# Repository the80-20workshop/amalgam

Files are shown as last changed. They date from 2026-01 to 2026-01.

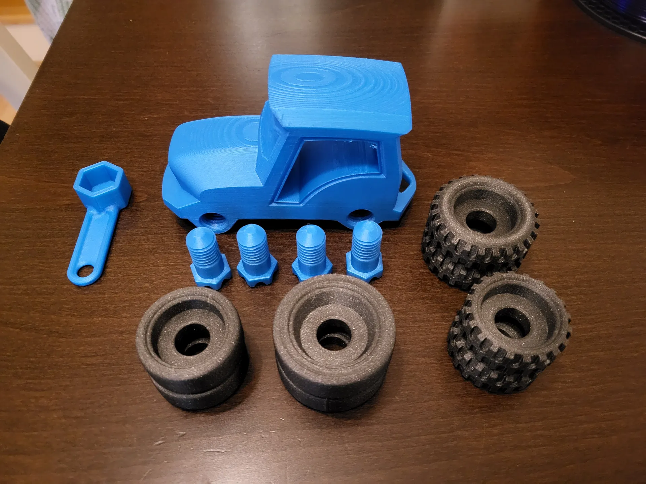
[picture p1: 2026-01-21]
docs/reference/ai-conversations/17003388837447721058862837478401.webp

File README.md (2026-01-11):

# Neo-Darwin

### A 2026 RepRap Reference Specification

**High-Mass, Low-Cost, Total Control.**

---

## 🚜 The Tractor is Coming

Neo-Darwin is a reimagining of the 2007 RepRap Darwin — a high-mass, fully parametric 3D printer built from M12 threaded rod, salvaged components, and open-source intelligence.

**Expected Release:** Q2/Q3 2026

---

## The Philosophy

We build a **"Tractor with the Brain of a Racecar"** — using heavy, high-torque, battle-tested hardware and giving it extreme precision through Klipper.

| Feature | Target |
|---|---|
| **Price** | < $300 AUD |
| **Build Volume** | 250–300mm³ |
| **Accuracy** | ±0.1mm (Tier 3+) |
| **Speed** | 70–120mm/s |
| **Control** | 100% Local, No Cloud |

---

## The Lineage

* **[RepRap Darwin (2007)](https://reprap.org/wiki/Darwin):** The origin. We carry its name forward.
* **[Prusa i3 Rework (2013)](https://www.thingiverse.com/thing:119616):** The source of our geared extruder heritage.
* **[RepRap Mendel Revisited (2024)](https://www.thingiverse.com/thing:6783269):** A modern nod to the M12 skeleton.
* **[The 100](https://github.com/MSzturc/the100) / [The Rook](https://github.com/Kanrog/Rook) (2023):** Proof that Klipper makes DIY frames competitive.

---

## 🚀 Getting Started

Want to build Neo-Darwin parts?

1. **Clone the repository**:
   ```bash
   git clone https://github.com/neo-darwin-reprap/neo-darwin.git
   cd neo-darwin
   ```

2. **Build parts**:
   ```bash
   cd cad
   ./setup.sh
   ```

3. **Learn more**:
   - [BUILDING.md](BUILDING.md) - Complete build guide
   - [cad/README.md](cad/README.md) - CAD documentation

**Requirements:**
- Python 3.9+
- 4GB RAM (recommended)
- See [BUILDING.md](BUILDING.md) for platform-specific setup

## Status

| Component | Status |
|---|---|
| Manifesto | ✅ Complete |
| build123d Parametric Parts | 🔧 In Development |
| Klipper Configurations | 🔧 In Development |
| Assembly Documentation | ⏳ Planned |
| Reference Build | ⏳ Planned |

---

## Stay Updated

⭐ **Star this repo** to follow development.

📬 **Discussions** will open closer to release.

---

## License

**GNU GPL v3** — The same license used by the original RepRap Darwin.

---

> *If you want a printer, buy one. If you want the Red Pill, build this.*

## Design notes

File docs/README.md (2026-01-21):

# Neo-Darwin Documentation

This directory contains all project documentation for Neo-Darwin.

## Documentation Structure

```
docs/
├── adr/           # Architecture Decision Records (formal decisions)
├── analysis/      # Engineering calculations and analysis
├── articles/      # Long-form thought pieces
├── deep-dives/    # Design exploration documents
├── guides/        # Tier-specific build guides
│   └── klipper/   # Klipper host setup guides
└── reference/     # Historical AI conversations (archival)
```

---

## Quick Navigation

### Getting Started

| Document | Description |
|---|---|
| [../MANIFESTO.md](../MANIFESTO.md) | Project overview and quick-start |
| [../PHILOSOPHY.md](../PHILOSOPHY.md) | The "Tractor" philosophy |
| [../REFERENCE-SPEC.md](../REFERENCE-SPEC.md) | Hardware specification |
| [../BUILDING.md](../BUILDING.md) | CAD/STL generation |

### Architecture Decisions

| ADR | Topic |
|-----|---|
| [adr/000](adr/000-engineering-philosophy.md) | Engineering Philosophy |
| [adr/001](adr/001-m10-skeleton.md) | M10 Frame Skeleton |
| [adr/019](adr/019-pitan-extruder.md) | Pitan Extruder |
| [adr/README.md](adr/README.md) | Full ADR index |

### Deep Dives

Design exploration documents that informed the ADRs:

| Document | Topic |
|---|---|
| [tractor_00](deep-dives/tractor_00_decision_guide.md) | Decision overview |
| [tractor_01](deep-dives/tractor_01_frame_and_assembly.md) | Frame design (M10 rationale) |
| [tractor_06](deep-dives/tractor_06_extruder_decision.md) | Extruder selection (Pitan) |
| [deep-dives/README.md](deep-dives/README.md) | Full index |

### Engineering Analysis

| Document | Topic |
|---|---|
| [rod-sag-analysis](analysis/rod-sag-analysis.md) | Smooth rod deflection |
| [max-safe-acceleration](analysis/max-safe-acceleration.md) | Motion limits |

### Build Guides

| Guide | Description |
|---|---|
| [guides/README.md](guides/README.md) | Tier system overview |
| Tier 3 Guide | Reference Spec (coming soon) |
| Tier 2 Guide | Dual donor (coming soon) |
| Tier 1 Guide | Single donor (coming soon) |

---

## Document Relationships

```
MANIFESTO.md (Quick Start)
    │
    ├── PHILOSOPHY.md (Why we build tractors)
    │
    ├── REFERENCE-SPEC.md (What we build)
    │       │
    │       └── docs/adr/ (Formal decisions)
    │               │
    │               └── docs/deep-dives/ (Exploration that led to decisions)
    │
    ├── BUILDING.md (How to generate parts)
    │       │
    │       └── cad/config.py (Parametric configuration)
    │
    └── docs/guides/ (How to build each tier)
            │
            └── docs/analysis/ (Engineering calculations)
```

---

## Reference Material

The `reference/` folder contains historical AI conversation logs and planning documents. These are preserved for context but are not actively maintained.

- `reference/ai-conversations/` - Raw design discussions
- `reference/planning/` - Project tracking documents

---

## Contributing

When adding documentation:

1. **New ADR:** Use `adr/template.md`, number sequentially
2. **Design exploration:** Add to `deep-dives/`, reference from ADR
3. **Analysis:** Add to `analysis/`, include calculations
4. **Build guide:** Add to `guides/`, follow tier structure

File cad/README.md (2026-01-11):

# Neo-Darwin CAD Directory

This directory contains all CAD-related files for Neo-Darwin 3D printer project.

## Quick Decision Guide

| Situation | What to Run |
|---|---|
| New user, first clone | `./setup.sh` (creates config + builds) |
| Have config.py, just build | `./build.sh build_all` |
| Want to change config | `./configure.py` then `./build.sh build_all` |
| Just updated repo | `./build.sh build_all` |

## Quick Start - For Testing

If you want to test with only the existing parts:

```bash
./build.sh build_all
```

## Quick Start - Full Setup

### Option 1: First-Time Setup (Recommended for New Users)

**Best for:** New users, first time cloning the repo

```bash
./setup.sh
```

The setup wizard will:
1. Detect your operating system (Linux/macOS/Windows)
2. Check for Python 3.9+ installation
3. Optionally install uv (fast Python package manager)
4. Set up Python environment
5. Install required packages
6. Run configuration wizard (creates `config.py`)
7. Build all parts

**Cross-platform support:**
- macOS: Works with Homebrew Python or official installer
- Linux: Works with system Python or distribution packages
- Windows: Works via Git Bash, WSL, or PowerShell

**Graceful failure:**
- If Python is not found, gives platform-specific installation instructions
- Script does NOT install Python automatically (~100-200MB)
- Always offers web interface as alternative (coming soon)

**After this:** You have `config.py` created and all parts built.

### Option 2: Just Build Parts

**Best for:** Already have `config.py` from previous build

```bash
./build.sh build_all
```

**What happens:**
- Checks for `.venv` and activates it if needed
- Installs dependencies if not found
- Builds all parts using your existing `config.py`

**Note:** If `config.py` doesn't exist, you'll get an error. Use `./configure.py` to create it.

### Option 3: Change Configuration

**Best for:** Want to modify printer settings

```bash
# Just run configuration wizard (backs up existing config)
./configure.py

# Then rebuild with new settings
./build.sh build_all
```

**What happens:**
- Asks configuration questions interactively
- Backs up existing `config.py` to `config.py.backup`
- Creates new `config.py` with your changes
- `build.sh` will use the new config

### Option 4: Manual Control

**Best for:** Experienced users, want full control

```bash
cd cad

# Create and activate virtual environment (if needed)
python3 -m venv .venv
source .venv/bin/activate  # Windows: .venv\Scripts\activate

# Install dependencies (optional - build.sh will do this if missing)
# Uses pyproject.toml (modern standard)
pip install -e .

# Run configuration wizard (or edit config.py directly)
./configure.py

# Build all parts
./build.sh build_all
```

**Note:** The build script automatically:
- Checks for `.venv` and activates it if needed
- Installs dependencies from pyproject.toml if not found
- Uses `uv` if available for faster installs

## Configuration

Three ways to configure:

1. **Interactive wizard** (recommended for new users):
   ```bash
   ./configure.py
   ```
   - Asks questions step by step
   - Backs up existing config to `config.py.backup`

2. **Manual edit**:
   - Edit `config.py` directly
   - Reference `config.py.example` for all available options

3. **Example file**:
   - `config.py.example` shows full configuration structure
   - Copy to `config.py` and customize

**Important:** `config.py` is ignored by git (keep your settings private).
Use `config.py.example` as reference for all available settings.

Key configuration parameters:
- `BUILD_VOLUME` - X, Y, Z dimensions
- `M12_FIT_DIA` - M12 rod diameter with lumpy factor
- `EXTRUDER_TYPE` - "WADE" or other
- `TRIPLE_Z` - Enable/disable triple Z system
- `Z_MOUNT_PATTERN` - Z-motor mounting configuration

## Dependencies

- Python 3.9+
- build123d
- numpy

See `requirements.txt` for specific versions.

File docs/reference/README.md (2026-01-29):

# Reference Documentation

This folder contains **factual reference materials** for Amalgam: specifications, compatibility data, and technical reference tables. Use this when looking up specs, verifying printer compatibility, or understanding component requirements.

## Contents

- **donor-printer-guide.md** — Comprehensive guide to donor printer compatibility
  - Fitness tiers (Tier 1/2/3) for each printer model
  - What components are scavengeable from each donor
  - Frame type, bed size, Z-travel specs
  - Mixed-donor combinations and recommendations
  - Cost reality check: when NOT to scavenge
  - Start here if selecting donor printers

- **parts-sourcing-guide.md** — How to source missing/failed parts
  - How to spot counterfeits and duds on AliExpress/Temu/eBay
  - Common pitfalls (wrong pitch leadscrew, fake bearings, etc.)
  - Platform comparison and sourcing strategy
  - Budget planning and decision tree
  - Use this if a donor part fails during build

- **MASTER_PARTS_LIST.md** — Complete bill of materials for all configurations
  - By frame path (Darwin, S-Core, V-Core)
  - By electronics configuration (Dual-MCU, SKIPR)
  - Part sourcing notes and costs

- **RENAME-TRACKING.md** — Project rename history
  - Tracks Neo-Darwin → Amalgam renaming
  - Useful for cross-referencing old documentation

- **Assembly_Manual_Trident.pdf** — Reference material from Voron Trident
  - Not Amalgam-specific, but useful for understanding Z-drop architecture
  - Reference only; see guides/ for Amalgam assembly instructions

## Related Documentation

- **Specifications & Decisions** → See `docs/adr/` (Architecture Decision Records)
- **Build Instructions** → See `docs/guides/` (step-by-step assembly)
- **Technical Validation** → See `docs/analysis/` (calculations and measurements)
- **Design Exploration** → See `docs/deep-dives/` (historical design thinking)

## Legacy Documentation

- **legacy/neo-darwin-manifesto-updates.md** — Historical project rename notes (archived)

---

*Use this folder for factual reference; see guides/ for instructional material.*

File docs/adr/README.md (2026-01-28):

# Amalgam Architecture Decision Records (ADRs)

This directory contains all Architecture Decision Records (ADRs) for the Amalgam project. Each ADR documents a significant engineering decision, including context, alternatives, rationale, and consequences.

## How to Read This Directory

ADRs are numbered chronologically in order of creation (000-021). However, for understanding the project's engineering philosophy:

1. **Start with ADR-000**: Engineering Philosophy and "Tractor" principles
2. **Read Core Hardware ADRs**: Foundation (001), motion (021), extruder (019), hotend (004)
3. **Read Motion & Leveling ADRs**: Triple-Z (005), puck system (009, 010)
4. **Read Electronics ADRs**: Mainboard (012), drivers (013), CAN bus (007)
5. **Read Tooling/Software ADRs**: CAD (017), documentation (018)

Note: Some ADRs are superseded (003→021, 002→019, 006→014). Superseded ADRs are preserved for decision history.

## ADR Index

### Foundational ADRs

| ADR | Title | Status | Summary |
|-----|---|---|---|
| [ADR-000](000-engineering-philosophy.md) | Engineering Philosophy (20 Years of RepRap Wisdom) | Accepted | Core principles: Mass, Software, Gearing, Amalgam Square trade-offs |
| [ADR-001](001-m10-skeleton.md) | M10 Threaded Rod Skeleton | Accepted | Steel frame for mass damping and rigidity (M10 over M12 for practicality) |
| ~~[ADR-002](002-greg-wade.md)~~ | ~~Greg's Wade Geared Extruder~~ | **Archived** | Superseded by ADR-019 (Pitan) |
| ~~[ADR-003](003-smooth-rods.md)~~ | ~~Smooth Rods vs Linear Rails~~ | **Superseded** | Superseded by ADR-021 (Dual-Rod Motion System) |
| [ADR-004](004-v6-cht.md) | E3D V6 Hotend with CHT Nozzle | Accepted | Standard V6 with CHT clone nozzle for high flow without ooze |

### Motion & Leveling ADRs

| ADR | Title | Status | Summary |
|-----|---|---|---|
| [ADR-005](005-triple-z.md) | Triple-Z Kinematic Leveling | Accepted | 3 independent Z-motors for automated bed leveling |
| ~~ADR-006~~ | Z-Probe Selection (Legacy) | **Archived** | Superseded by ADR-014 |
| [ADR-009](009-puck-system.md) | Modular Puck & Spider Bed System | Accepted | Standardized mounting for toolheads, bed supports, Z-motors |
| [ADR-010](010-floating-z-puck.md) | Floating Z-Puck System | Accepted | Parametric Z-motor pucks for any bed size, double-nut anchor |
| ~~[ADR-020](020-dual-8-scavenger.md)~~ | ~~Dual-8 Scavenger Variant~~ | **Superseded** | Analysis merged into ADR-021 |
| [ADR-021](021-dual-rod-motion-system.md) | Dual-Rod Motion System | **Accepted** | Dual 8mm vertical stacking as reference spec (supersedes ADR-003, ADR-020) |
| [ADR-022](022-linear-bearings.md) | Linear Bearing Selection | **Accepted** | LM8LUU for X, LM8UU for Y/Z; scavenged bearing protocol |
| [ADR-023](023-z-drop-architecture.md) | Z-Drop Architecture | **Accepted** | Bed moves only in Z, XY gantry at fixed height; enables Triple-Z |
| [ADR-024](024-heated-bed-size.md) | Heated Bed Size Selection | **Accepted** | 220×220mm reference (Anet A8); analysis of scavengeable bed sizes |
| [ADR-025](025-multi-frame-architecture.md) | Multi-Frame Architecture | **Accepted** | Darwin (M10), S-Core, V-Core paths; MDF base; tier system update |
| [ADR-026](026-donor-fitness-constraints.md) | Donor Fitness & Frame Constraints | **Accepted** | Bed size and Z-height fitness tiers; stability limits; heatbed swap guidance |

### Foundation & Electronics ADRs

| ADR | Title | Status | Summary |
|-----|---|---|---|
| [ADR-007](007-can-bus.md) | CAN Bus Architecture | Accepted | Future-proofing for toolhead boards, ERCF, modular expansion |
| [ADR-008](008-spider-bed.md) | Spider Bed Support System | Accepted | Modular 3-part bed support for printing on small donor machines |
| [ADR-011](011-laminated-plinth.md) | Laminated Plinth Baseboard | Accepted | Constrained Layer Damping (CLD) foundation for Tier 3 Reference Spec |
| [ADR-012](012-mainboard-host-architecture.md) | Mainboard & Host Architecture | Accepted | MKS SKIPR Reference Spec, multi-MCU salvage paths |
| [ADR-013](013-drivers-endstops.md) | Driver & Endstop Strategy | Accepted | TMC2209 with mechanical switches, Z-max safety switch |
| [ADR-016](016-electronics-mounting.md) | Electronics & PSU Mounting Strategy | Accepted | Direct MDF coupling (Reference) vs printed puck frames |

### Tooling & Probing ADRs

| ADR | Title | Status | Summary |
|-----|---|---|---|
| [ADR-014](014-z-probe-selection.md) | Z-Probe Selection (SuperPINDA vs BLTouch) | Accepted | SuperPINDA for Reference Spec (metal beds), BLTouch for scavenger (universal) |
| [ADR-015](015-single-toolhead.md) | Single Toolhead Architecture | Accepted | Base spec single toolhead, ERCF v2 expansion, manual puck swaps for laser/pen |

### Software & Tooling ADRs

| ADR | Title | Status | Summary |
|-----|---|---|---|
| [ADR-017](017-parametric-cad-system.md) | Parametric CAD System | Accepted | build123d over OpenSCAD/FreeCAD/TinkerCAD for BREP and Python ecosystem |
| [ADR-018](018-documentation-system.md) | Documentation & Assembly Guide System | Accepted | Quarto for literate CAD, professional PDFs, conditional content |
| [ADR-019](019-pitan-extruder.md) | Pitan Extruder | Accepted | Single-drive, scavengeable NEMA17, $4-10 cost (supersedes ADR-002) |

## ADR Categories

### Core Hardware (001, 004, 019, 021, 025)
Frame, extruder, hotend, and motion system - the physical foundation of the machine.
- ADR-025: Multi-Frame Architecture (Darwin, S-Core, V-Core paths - all on MDF base)
- ADR-001: M10 Frame Skeleton (Darwin path primary)
- ADR-021: Dual-Rod Motion System (Dual 8mm vertical stacking - Darwin/S-Core)
- ADR-004: E3D V6 + CHT Hotend
- ADR-019: Pitan Extruder (Reference Spec)

### Motion & Leveling (005, 007-010)
Z-axis leveling, CAN bus, modular bed, and Z-motor mounting - kinematic accuracy and foundation.

### Foundation & Electronics (008-009, 011-013, 016)
Baseboard, mainboard, drivers, endstops, and electronics mounting - "Brain" and power.

### Tooling & Probing (014-015)
Z-probe selection and toolhead architecture - single/multi-material capability.

### Software & Tooling (017-018)
CAD system and documentation - parametric design and assembly guides.

## Reading Order for New Contributors

If you're new to Amalgam and want to understand the engineering decisions:

1. **Engineering Philosophy** → ADR-000
2. **Frame & Donor Selection** → ADR-025 (Multi-Frame: Darwin, S-Core, V-Core paths)
3. **Donor Fitness & Constraints** → ADR-026 (Bed size, Z-height, stability limits)
4. **Hardware Foundations** → ADR-001 (M10 Frame), ADR-019 (Pitan Extruder), ADR-004 (Hotend)
5. **Motion System** → ADR-021 (Dual-Rod Motion), ADR-005 (Triple-Z), ADR-024 (Bed Size)
6. **Electronics** → ADR-012, 013
7. **Probing** → ADR-014
8. **Advanced Features** → ADR-007, 009, 011, 015, 016
9. **Tooling** → ADR-017, 018

**For Donors:** Start with ADR-025, then ADR-026 for fitness constraints. See `docs/reference/donor-printer-guide.md` for per-printer details.

Notes:
- ADR-002 (Greg's Wade) is archived—see ADR-019 for the current extruder decision.
- ADR-003 (Smooth Rods) is superseded—see ADR-021 for the current motion system decision.

## ADR Template

When creating a new ADR, use the template at `template.md`:

```markdown
# ADR-XXX: [Title]

## Status
Accepted | Proposed | Deprecated | Superseded

## Context
What is the issue we're facing that motivated this decision?

## Decision
What is the change we're proposing?

## Consequences
What becomes easier or more difficult to do because of this change?

## BOM Implications (Generic)
What parts are affected by this decision?

## References
Links to relevant documentation, AI conversations, or external resources.
```

## ADR Lifecycle

- **Proposed**: Initial draft, under discussion
- **Accepted**: Decision finalized, implemented
- **Deprecated**: Still in use, but recommended against for new builds
- **Superseded**: Replaced by newer ADR, kept for decision history (links forward to replacement)
- **Archived**: No longer relevant, kept for historical reference only

## Version Control

All ADRs are tracked in git. Changes to accepted ADRs should be:
- Clearly explained in commit messages
- Discussed with project maintainers before merging
- Documented with rationale for the change

## References

- **Project Manifesto**: `MANIFESTO.md` - High-level philosophy and goals
- **Reference Documentation**: `docs/reference/` - Detailed technical discussions
- **AI Conversations**: `docs/reference/ai-conversations/` - Raw design discussions
- **CAD System**: `cad/` - build123d parametric scripts
- **Build Instructions**: `docs/planning/` - Assembly and construction guides

---

**"The code handles the permutations; the iron handles the quality."**

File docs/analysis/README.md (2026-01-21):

# Engineering Analysis

This folder contains engineering calculations and analysis that inform Neo-Darwin design decisions.

These documents provide the mathematical foundation for understanding trade-offs in the design.

## Contents

| Document | Topic | Key Insight |
|---|---|---|
| [rod-sag-analysis.md](rod-sag-analysis.md) | Smooth rod deflection | M8 vs M10 at various spans |
| [max-safe-acceleration.md](max-safe-acceleration.md) | Motion limits | Toolhead mass vs acceleration |

## Future Analysis

The following analyses are planned for the engineering analysis TUI tool:

- **Frame rigidity calculator**: M8/M10/M12 threaded rod stiffness
- **Bed size optimizer**: Heat bed size vs frame dimensions
- **Motor torque requirements**: Extruder gear ratios vs filament resistance
- **Resonance frequency estimator**: For Input Shaping configuration

## Using These Calculations

These analyses are inputs to:
- **ADRs**: Justifying design choices
- **config.py**: Setting parametric defaults
- **Analysis TUI**: Interactive build assessment tool (planned)

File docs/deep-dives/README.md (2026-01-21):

# Deep Dives

This folder contains in-depth design explorations and discussions that led to the formal Architecture Decision Records (ADRs).

**Relationship to ADRs:**
- **ADRs** (`docs/adr/`) = Formal, structured decisions with Status/Context/Decision/Consequences
- **Deep Dives** = The thinking process, analysis, and exploration that informed those decisions

## Contents

| Document | Topic | Related ADRs |
|---|---|---|
| [tractor_00_decision_guide.md](tractor_00_decision_guide.md) | Overview of key decisions | Multiple |
| [tractor_01_frame_and_assembly.md](tractor_01_frame_and_assembly.md) | M10 frame design, squaring | ADR-001 |
| [tractor_02_xy_axis_system.md](tractor_02_xy_axis_system.md) | X-Y motion, smooth rods | ADR-003 |
| [tractor_03_motor_mounts_vibration.md](tractor_03_motor_mounts_vibration.md) | Motor mounting, damping | ADR-000, ADR-011 |
| [tractor_04_xgantry_design_decision.md](tractor_04_xgantry_design_decision.md) | X-gantry architecture | ADR-003 |
| [tractor_05_psu_configurations.md](tractor_05_psu_configurations.md) | PSU options for tiers | ADR-012, ADR-016 |
| [tractor_06_extruder_decision.md](tractor_06_extruder_decision.md) | Pitan selection, single-drive | ADR-019 |

## Reading Order

For understanding the Neo-Darwin design:

1. Start with `tractor_00_decision_guide.md` for an overview
2. Read the ADRs for formal decisions
3. Return to specific deep dives for detailed rationale

## Contributing

When making significant design decisions:
1. Document the exploration in a deep dive
2. Create or update the relevant ADR
3. Cross-reference between them

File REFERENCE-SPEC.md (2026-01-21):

# Neo-Darwin Reference Specification

**The "Blessed" Hardware Configuration for 2026**

This document defines the specific hardware choices for the Neo-Darwin. For the philosophy behind these choices, see [PHILOSOPHY.md](PHILOSOPHY.md). For build instructions, see [BUILDING.md](BUILDING.md).

---

## Quick Reference

| Component | Reference Spec | ADR |
|---|---|-----|
| **Frame Skeleton** | M10 Threaded Rods (Bright Zinc or Galvanized) | [ADR-001](docs/adr/001-m10-skeleton.md) |
| **Smooth Rods (X-Y)** | M10 Precision Ground | [ADR-003](docs/adr/003-smooth-rods.md) |
| **Smooth Rods (Z)** | M8 (sufficient with Triple-Z) | [ADR-003](docs/adr/003-smooth-rods.md) |
| **Extruder** | Pitan (3:1 geared, single-drive) | [ADR-019](docs/adr/019-pitan-extruder.md) |
| **Hotend** | E3D V6 + CHT Clone Nozzle | [ADR-004](docs/adr/004-v6-cht.md) |
| **Z-System** | Triple-Z Independent Motors | [ADR-005](docs/adr/005-triple-z.md) |
| **Z-Probe** | SuperPINDA (Reference) / BLTouch (Scavenger) | [ADR-014](docs/adr/014-z-probe-selection.md) |
| **Controller** | MKS SKIPR (Integrated Klipper) | [ADR-012](docs/adr/012-mainboard-host-architecture.md) |
| **Drivers** | TMC2209 | [ADR-013](docs/adr/013-drivers-endstops.md) |

---

## Project Goals

* **Price Target:** < $300 AUD (Beating the Bambu A1 Mini)
* **Build Volume:** ~250mm³ (Equalling or Exceeding the Prusa MK4)
* **Quality:** High-precision via Klipper Input Shaping and 3-Point Z-Tilt
* **Speed:** 70-120mm/s with tuned Input Shaping
* **Accuracy:** ±0.1mm dimensional consistency (Tier 3+ with M10 rods)
* **Reliability:** Prints identically on Day 1000 as on Day 1

---

## Before You Build: The 5 Key Decisions

Neo-Darwin operates within a wide envelope. Before purchasing materials:

1. **Salvage or Buy Rods?** (M8 salvage vs M10 new)
2. **Belted-Z or Triple-Z?** (1 motor vs 3 motors)
3. **Single Board or Multi-MCU?** (MKS SKIPR vs salvaged boards)
4. **Extruder Choice?** (Pitan reference vs Wade heritage vs what you have)
5. **Mono or Multi-Color?** (Standard vs ERCF expansion)

These choices determine your tier, budget, and experience level.

---

## The Hardware Stack

### The Skeleton: M10 Threaded Rods

M10 was chosen over M12 for practicality:

| Feature | M8 | M10 | M12 |
|---|-----|-----|-----|
| Rigidity vs M8 | 1× | 3× | 5× (overkill) |
| Wrench Size | 13mm | 17mm (universal) | 19mm (less common) |
| Printability | Easy | Easy | Bulky brackets |

* **Bright Zinc** for smoothness (`lumpy_factor = 0.2`)
* **Hot-Dip Galvanized** for rust-proofing (`lumpy_factor = 0.5+`)

### The Heart: Pitan Extruder

The Pitan (Printable Titan) is our reference extruder:

* **Single-Drive Design:** No gear mesh artifacts (same principle as Bambu Lab)
* **3:1 Gear Ratio:** Adequate torque for PLA, PETG, careful TPU
* **Scavengeable Motor:** Uses standard NEMA17 from any donor printer
* **Fully Printable:** Body and gears can be reprinted
* **Cost:** $4-10 AUD total

**Heritage Option:** Greg's Wade with pancake NEMA17 (PLA/PETG only)
**Ultra-Scavenger:** MK8 direct drive (if you have one)

See [ADR-019](docs/adr/019-pitan-extruder.md) for full rationale.

### The Lungs: E3D V6 + CHT Nozzle

* **E3D V6** (or high-quality clone) for thermal stability
* **CHT Clone Nozzle** increases flow by 50% without ooze
* Prioritizes detail and ERCF compatibility over raw speed

### The Brain: MKS SKIPR

The cleanest "all-in-one" path:

* **Integrated Klipper Host:** No external Raspberry Pi needed
* **eMMC Storage:** More reliable than MicroSD cards
* **7 Driver Slots:** Perfect "6+1" for Triple-Z + Extruder
* **Native CAN Bus:** Future-proof for toolhead boards

**Alternative Paths:**
* **Path A (Pure Scavenger):** Multi-MCU with salvaged boards + laptop
* **Path B (Modular):** FYSETC Spider + Raspberry Pi

### The Leveling: Triple-Z Independent

Three independent Z-motors for automated Klipper Z-Tilt calibration:

* **The "Neo" Path:** Automated calibration via `Z_TILT_ADJUST`
* **The "Tractor" Path:** Single motor + belt (manual leveling once)

### The Motion: Smooth Rods

| Axis | Reference Spec | Scavenger Option |
|---|---|---|
| **X-Y** | M10 Precision Ground | M8 from donor |
| **Z** | M8 (Triple-Z reduces deflection concerns) | M8 |

**Why Not Rollers?**
1. Can't mount to threaded-rod frame
2. Rollers wear out and flat-spot
3. 10mm smooth rods on M10 frame = "forever machine"

---

## Tiered BOM Strategy

All prices estimated in AUD (2026).

| Category | Tier 1 (Scrap) | Tier 2 (Hybrid) | Tier 3 (Reference) |
|---|---|---|---|
| **Logic Path** | Single-Z Belt | Triple-Z | Triple-Z + SKIPR |
| **Mainboard** | Salvaged | Salvaged | MKS SKIPR |
| **Klipper Host** | Laptop ($0) | RPi Zero 2W (~$32) | Integrated |
| **Linear Motion** | Salvaged M8 | Salvaged M8 | Buy M10 (~$65) |
| **Motors** | 4 Salvaged | 4 Salvaged + 2 New | 4 Salvaged + 2 New |
| **Skeleton** | M10 Hardware (~$40) | M10 Hardware (~$40) | M10 Hardware (~$40) |
| **TOTAL** | **~$80** | **~$200** | **~$270** |

### Tier Recommendations

| Tier | Experience |
|---|---|
| Tier 1 | Set-and-monitor (manual tuning) |
| Tier 2 | Set-and-tune (ADXL required) |
| Tier 3 | Set-and-forget (recommended) |

---

## Component Shopping List

### Hotend Stack
* **Primary:** TriangleLab or Mellow E3D V6 Clone (All-Metal)
* **Nozzles:** 0.4mm Brass, 0.6mm Brass, 0.4mm CHT Clone

### Gearing & Motion
* **Extruder:** Pitan printed parts + MK8 drive gear ($2-5)
* **Bearings:** 12× LM10UU (for M10) or LM8UU (for M8)
* **Smooth Rods:** 10mm Precision Ground (don't buy 8mm if buying new)

### Brain Essentials
* **Controller:** MKS SKIPR (~$85)
* **Drivers:** TMC2209 (often included or ~$6 each)
* **Resonance Sensor:** ADXL345 (~$18, required for Input Shaping)
* **Toolhead Sensor:** KW11-3Z Microswitch ($2, for ERCF)

### The "Tractor" Supplies
* **Thermal Bonding:** High-Temp Red RTV Silicone (for potting thermistor)

---

## Z-System Permutations

| Decision | Option A (Neo) | Option B (Tractor) |
|---|---|---|
| Z System | Triple-Z | Belted-Z |
| Motors | 3 | 1 |
| Board Requirement | 6+ drivers | 4 drivers |
| Experience | Auto-level | Manual once |
| Tier | 2+ | 1 |

---

## Multi-Color Expansion: ERCF v2

The Enraged Rabbit Carrot Feeder is the official multi-color expansion:

* **Total Sovereignty:** Fully 3D-printable, standard hardware
* **Modular Scale:** Start with 4 colors, expand to 12+
* **Scavenger Edge:** Uses NEMA17 motors and 608 bearings

| Component | Est. Cost (AUD) |
|---|---|
| ERCF v2 (8-Gate) | ~$120-150 |
| Filametrix Cutter | ~$5 |
| ERCT Buffer | ~$15 |

---

## Safety Requirements

* **Z-Max Physical Stop:** Mandatory microswitch at Z-max prevents bed-drop
* **Electrical:** Verify all salvaged wiring is intact
* **Thermal:** Allow hotend and bed to cool before touching
* **Ventilation:** Operate in well-ventilated area

---

## Self-Healing Machine Strategy

### The "Cold-Spare" Principle

The Neo-Darwin is self-replicating. Maintain a "Vitamin Box" containing:

* Complete set of Pitan gears (printed)
* Spare MK8 drive gear or hobbed bolt
* Spare thermistor (NTC 100K)
* 5× 0.4mm nozzles
* 4010 ball-bearing fan

### Maintenance Checklist (Every 1000 Hours)

- [ ] Inspect gear teeth for wear
- [ ] Clear plastic dust from drive gear
- [ ] Verify frame nuts haven't vibrated loose
- [ ] Re-run `SHAPER_CALIBRATE` if machine was moved

---

## High-Level Assembly Overview

1. **Frame Construction:** Cut M10 rods, assemble with printed corners, verify square
2. **Gantry & X-Axis:** Mount X-axis to vertical pillars, install Pitan extruder
3. **Triple-Z Foundation:** Install Z-motors, leadscrews, and Spider bed support
4. **Wiring & Electronics:** Mount SKIPR, wire motors (Z1, Z2, Z3 on independent drivers)
5. **Klipper Setup:** Flash `printer.cfg`, verify with `STEPPER_BUZZ`

For detailed instructions, see [docs/guides/](docs/guides/).

---

## Related Documents

* [PHILOSOPHY.md](PHILOSOPHY.md) - The engineering philosophy
* [BUILDING.md](BUILDING.md) - CAD/STL generation
* [docs/adr/](docs/adr/) - Architecture Decision Records
* [docs/deep-dives/](docs/deep-dives/) - Design exploration documents
* [docs/guides/](docs/guides/) - Tier-specific build guides

---

*"The code handles the permutations; the iron handles the quality."*

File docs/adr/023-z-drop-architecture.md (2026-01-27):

# ADR-023: Z-Drop Architecture

## Status
Accepted

## Context

A 3D printer must move the nozzle relative to the print surface in three axes. There are several ways to achieve this:

### Motion Architecture Options

**1. Bed-Slinger (Prusa i3 style)**
- Bed moves in Y, gantry moves in X, Z lifts gantry or bed
- Common in: Prusa MK3, Ender 3, Anet A8
- Characteristic: Bed swings back and forth during printing

**2. Z-Drop / Moving Bed Z (Voron Trident style)**
- XY gantry at fixed height, bed moves only in Z
- Common in: Voron Trident, RatRig V-Core
- Characteristic: Bed drops down as layers are printed

**3. Gantry-Rise / Fixed Bed (Voron 2.4 style)**
- Bed fixed at bottom, entire XY gantry rises in Z
- Common in: Voron 2.4, some industrial machines
- Characteristic: Gantry climbs upward during printing

**4. CoreXZ (Voron Switchwire style)**
- Bed moves in Y, toolhead moves in X and Z via CoreXZ kinematics
- Common in: Voron Switchwire, converted Enders
- Characteristic: Hybrid approach, complex belt paths

### Neo-Darwin Constraints

- **Triple-Z kinematic leveling** (ADR-005) - requires independent Z control
- **M10 threaded rod frame** (ADR-001) - heavy, rigid, not optimized for gantry climbing
- **Scavenger philosophy** - must work with donor printer parts
- **Heavy heated bed** - 235×235mm aluminum/glass bed has significant mass
- **"Tractor" philosophy** - mass for stability, software for precision

## Decision

We choose **Z-Drop Architecture** where the bed moves only in Z and the XY gantry operates at a fixed height near the top of the frame.

### Why Z-Drop?

#### 1. Triple-Z Synergy

Z-drop + Triple-Z is mathematically elegant:

| Architecture | Auto-Leveling Method | Motors Required |
|---|---|---|
| Z-Drop + Triple-Z | Z_TILT_ADJUST (tilt bed to match gantry) | 3 Z-motors |
| Gantry-Rise + Fixed Bed | Quad Gantry Level (tilt gantry to match bed) | 4 Z-motors |

**Three points define a plane.** With Z-drop, we tilt a static bed to match the gantry - simple geometry, fewer motors, proven by Voron Trident.

With gantry-rise, we'd need to tilt the entire moving XY assembly using 4 motors (Quad Gantry Leveling) - more complex, more parts, harder to scavenge.

#### 2. Center of Gravity Stability

As the print progresses:

**Z-Drop:**
```
Start of print:          End of print:
┌─────────────┐          ┌─────────────┐
│   [Gantry]  │          │   [Gantry]  │
│             │          │             │
│   [Bed+Print at top]   │             │
│             │          │             │
└─────────────┘          │   [Bed+Print at bottom]
     CoG: High           └─────────────┘
                              CoG: LOW ✓
```

The heaviest part (bed + growing print) moves **toward** the 36mm MDF base. Center of gravity stays low = more stability.

**Gantry-Rise:**
```
Start of print:          End of print:
┌─────────────┐          ┌─────────────┐
│             │          │   [Gantry at top]
│             │          │             │
│   [Gantry at bottom]   │             │
│   [Bed]     │          │   [Bed]     │
└─────────────┘          └─────────────┘
     CoG: Low                 CoG: HIGH ✗
```

Heavy gantry (motors, extruder, rods) climbs to top of frame = pendulum effect, frame flex amplified.

#### 3. Cable Management

| Aspect | Z-Drop | Gantry-Rise |
|---|---|---|
| Moving cables | Bed heater + thermistor (2 wires) | X motor, Y motors, extruder, fans, hotend, probe (10+ wires) |
| Cable chain | Simple, short | Long, complex, moves full Z height |
| Failure mode | Bed wire breaks (easy fix) | Toolhead wire breaks (printer stops) |

The "racecar brain" (toolhead with all its sensors and actuators) stays at fixed height. Only simple power wires to the bed need to flex.

#### 4. Scavenger Simplicity

| Component | Z-Drop | Gantry-Rise |
|---|---|---|
| Z drive | 3 standard leadscrews | 4 leadscrews + belt sync or 4 motors |
| Z rods | 2 vertical smooth rods | 4 corner rods or rails |
| Mechanics | Bed platform rises/falls | Entire gantry must climb frame |
| Donor parts | Leadscrews from any printer | Need matched quad setup |

Z-drop uses the simplest possible Z mechanics - vertical leadscrews and smooth rods that any donor printer provides.

#### 5. MDF Base Damping

The 36mm laminated MDF plinth (ADR-011) provides constrained layer damping. Z-drop keeps the heavy bed **close to the damping base** throughout printing:

- Print layer 1: Bed at top, but print mass is minimal
- Print layer 100: Bed lower, print mass increasing, closer to MDF damping
- Print layer 500: Bed near bottom, maximum mass, maximum damping benefit

This maximizes the effectiveness of Input Shaper calibration - resonances stay consistent because the mass stays near the damped base.

## Consequences

### Benefits

1. **Simpler Triple-Z**: 3 motors define a plane, no quad gantry complexity
2. **Stable center of gravity**: Heavy parts stay low throughout print
3. **Easy cable management**: Only bed wires move
4. **Scavenger-friendly**: Standard leadscrews, no custom gantry mechanics
5. **MDF damping synergy**: Heavy mass stays near damped base
6. **Proven design**: Voron Trident validates this architecture

### Trade-offs

1. **Taller frame**: Need Z-height for bed travel + clearance
2. **Bed drop risk**: Heavy bed can crash if power lost (see mitigation below)
3. **Bed heater wires**: Must accommodate Z travel (flexible cable or chain)
4. **Print removal**: Bed at bottom after tall prints (must raise to remove)

### Bed Drop Mitigation

Heavy beds can "back-drive" unpowered leadscrews and crash down. Mitigations:

1. **Leadscrew friction**: TR8×2 (2mm pitch) has enough friction to hold 235×235 bed
2. **Triple-Z distribution**: Load spread across 3 screws increases holding friction
3. **Anti-backlash nuts**: Add friction that helps hold position
4. **Software**: Klipper can park bed at safe height before shutdown
5. **Mechanical stop**: Optional hard stop at bottom of Z travel

For Neo-Darwin's 235×235mm bed (~500-800g with glass), the friction of 3 TR8×2 leadscrews is sufficient to prevent unpowered drop.

## Architectural Integration

### Relationship to Other ADRs

```
ADR-023: Z-Drop Architecture
    │
    ├── Enables → ADR-005: Triple-Z (3-motor bed leveling)
    │
    ├── Requires → ADR-008: Spider Bed Support (carries bed on Z)
    │
    ├── Informs → ADR-021: Dual-Rod Motion (XY at fixed height)
    │
    └── Benefits → ADR-011: Laminated Plinth (damping stays effective)
```

### Frame Layout

```
┌─────────────────────────────────────┐  ← Top of M10 frame
│                                     │
│  ┌─────────────────────────────┐    │  ← XY Gantry (FIXED HEIGHT)
│  │  Y-rods (dual per side)     │    │
│  │     [Plough on X-rods]      │    │
│  └─────────────────────────────┘    │
│                                     │
│         ↕ Z Travel (~250mm)         │
│                                     │
│  ┌─────────────────────────────┐    │  ← Bed Platform (MOVES IN Z)
│  │      [Heated Bed]           │    │
│  │   Z1 ─────┼───── Z2         │    │  ← Triple-Z leadscrews
│  │           Z3                │    │
│  └─────────────────────────────┘    │
│                                     │
└─────────────────────────────────────┘  ← 36mm MDF Plinth
```

### Motion Independence

**Critical design principle:** The XY gantry and Z-bed are **completely independent systems**.

- XY gantry never moves in Z
- Bed never moves in X or Y
- Z_TILT_ADJUST tilts the bed plane to match the gantry plane
- No mechanical coupling between XY and Z motion

This independence simplifies:
- Klipper configuration (separate stepper sections)
- Calibration (XY and Z tuned independently)
- Troubleshooting (isolate issues to one system)
- Scavenging (Z parts don't need to match XY parts)

## Alternatives Considered

### Alternative A: Bed-Slinger (Rejected)

Moving bed in Y (like Prusa i3):

**Pros:**
- Simpler frame (shorter in Y)
- Well-proven design
- Easy to scavenge (most donors are bed-slingers)

**Cons:**
- Heavy bed moving in Y causes ringing artifacts
- Limits print speed for quality
- Y-motor works harder (accelerating bed mass)
- Bed leveling more complex (bed moves during probe)

**Verdict:** Rejected. Moving heavy bed in Y contradicts "Tractor" philosophy of keeping mass stationary for quality.

### Alternative B: Gantry-Rise (Rejected)

Fixed bed at bottom, gantry climbs (like Voron 2.4):

**Pros:**
- Bed always accessible
- Excellent for enclosed chambers (heat rises to gantry)
- Premium feel

**Cons:**
- Requires 4 Z-motors for Quad Gantry Leveling
- Center of gravity rises during print
- Complex cable management (toolhead wires must travel full Z)
- Heavier gantry (carries more structure)
- Harder to scavenge (need 4 matched Z-motors)

**Verdict:** Rejected. QGL requires 4 motors vs Triple-Z's 3. Harder to scavenge, higher CoG during printing.

### Alternative C: CoreXZ (Rejected)

Bed moves in Y, toolhead moves in X and Z via crossed belts:

**Pros:**
- Compact design
- Good for conversions (Ender → Switchwire)

**Cons:**
- Still a bed-slinger (Y-axis bed movement)
- Complex belt paths
- Not compatible with M10 threaded rod frame
- Different lineage from Darwin/Mendel

**Verdict:** Rejected. Still has bed-slinger drawbacks, incompatible with frame philosophy.

## Implementation Notes

### Z Travel Calculation

```python
# From config.py
Z_TRAVEL = BUILD_VOLUME["Z"] + CLEARANCE
        = 250 + 30
        = 280mm minimum Z travel

FRAME_HEIGHT = Z_TRAVEL + GANTRY_HEIGHT + BED_THICKNESS + PLINTH_CLEARANCE
            = 280 + 80 + 40 + 30
            = 430mm internal height
```

### Leadscrew Positioning (for Z_TILT_ADJUST)

Optimal Triple-Z placement for Z_TILT_ADJUST:

```
        ┌─────────────────────┐
        │                     │
        │    Z3 (back-center) │
        │         ●           │
        │                     │
        │  ●               ●  │
        │ Z1               Z2 │
        │ (front-left) (front-right)
        └─────────────────────┘
```

**Spread as wide as possible** - maximizes the "lever arm" for tilt correction, improving accuracy.

### Klipper Configuration

```ini
[stepper_z]   # Z1 - front left
[stepper_z1]  # Z2 - front right
[stepper_z2]  # Z3 - back center

[z_tilt]
z_positions:   # Leadscrew positions
    30, 30     # Z1 front-left
    200, 30    # Z2 front-right
    115, 200   # Z3 back-center
points:        # Probe points (near leadscrews)
    30, 30
    200, 30
    115, 200
```

## References

- ADR-005: Triple-Z Independent Kinematic Leveling
- ADR-008: Spider Bed Support System
- ADR-011: Laminated Plinth Baseboard
- ADR-021: Dual-Rod Motion System
- [Voron Trident](https://vorondesign.com/voron_trident): Z-drop + Triple-Z reference
- [Voron 2.4](https://vorondesign.com/voron2.4): Gantry-rise + QGL reference
- docs/deep-dives/tractor_02_xy_axis_system.md: Detailed Z-drop implementation

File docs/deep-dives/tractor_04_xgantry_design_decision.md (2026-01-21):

# Neo-Darwin: X-Gantry Design Decision

## Engineering Decision Record

**Project:** Neo-Darwin 3D Printer  
**Component:** X-Axis Gantry System  
**Decision:** Parallel-Rail Sled ("The Plough")  
**Status:** Accepted  

---

## Executive Summary

After evaluating multiple X-gantry architectures including Cross-Rod (Eustathios/HercuLien), CoreXY variants, and the classic Cartesian sled, we selected the **Parallel-Rail Sled design** ("The Plough") for Neo-Darwin.

**Key Drivers:**
- Simplicity over speed
- Scavenger-friendly construction
- Maintainability by non-experts
- Authentic RepRap Darwin lineage
- Leverages M10 rod stiffness advantage

---

## Design Context

### Neo-Darwin Philosophy

Neo-Darwin is designed as:
- A "Tractor with a Racecar Brain" (heavy frame, smart software)
- A scavenger/junkstrap build using donor printers
- Quality-focused rather than speed-focused
- Maintainable by people with basic mechanical skills
- A spiritual successor to the original RepRap Darwin (2007)

### Hardware Constraints

| Component | Specification |
|---|---|
| Frame | M10 threaded rod on 36mm laminated MDF |
| X-Rails | M10 smooth rods (scavenged from photocopiers) |
| Span | ~380mm |
| Extruder | Pitan (Titan clone) direct drive |
| Hotend | E3D V6 |
| Controller | Klipper on dual MCU |
| Z-System | Triple-Z steppers with kinematic joints |
| Y-System | Dual Y-steppers with auto-squaring |

---

## Alternatives Considered

### Option A: Cross-Rod Gantry (Eustathios/HercuLien Style)

**Description:**  
Two rods for X and two for Y intersect at the toolhead. The toolhead "floats" at the crossing point, often called a "spider" carriage. This is sometimes called "Ultimaker-style."

```
    ════════════════════════  Y-Rod 1
           ╲         ╱
            ╲       ╱
             [HEAD]
            ╱       ╲
           ╱         ╲
    ════════════════════════  Y-Rod 2
    
    ║                      ║
    ║      X-Rods          ║
    ║   (perpendicular)    ║
```

**Pros:**
- Extremely light toolhead (only hotend moves in X-Y)
- Excellent for high-speed printing (500mm/s+)
- The "gold standard" for high-end rod-based DIY printers
- M10 rods would provide essentially zero sag at 380mm

**Cons:**
- Complex belt routing (crossed belts or dual belt systems)
- Requires precise geometry—belt path errors cause skew
- "Spider" carriage needs tight tolerances
- Harder to scavenge parts (specific pulley positions required)
- Klipper config more complex (`[hybrid_corexy]` or custom kinematics)
- More difficult to troubleshoot and repair
- Not in the Darwin/Mendel lineage

**Verdict:** Rejected—too complex for scavenger build philosophy.

---

### Option B: CoreXY / H-Bot

**Description:**  
Two motors work together via a continuous belt loop. Both motors spinning the same direction = Y movement. Opposite directions = X movement.

```
    [Motor A]═══════════════[Motor B]
              ╲           ╱
               ╲ Belts  ╱
                ╲     ╱
                 [HEAD]
                ╱     ╲
               ╱       ╲
              ╱         ╲
    ═══════════════════════════════
```

**Pros:**
- Both motors are stationary (not on gantry)
- Very light moving mass
- Excellent acceleration capability
- Popular design with extensive community support

**Cons:**
- Requires rigid frame (usually aluminum extrusion)
- Belt routing is complex and must be precise
- Misaligned belts cause "racking" (diagonal prints)
- Not compatible with threaded-rod frame philosophy
- Requires specific pulley stacks and belt lengths
- Harder to build from scavenged parts
- Completely different lineage from RepRap Darwin

**Verdict:** Rejected—incompatible with M10 threaded rod frame design.

---

### Option C: Parallel-Rail Sled ("The Plough") ✓ SELECTED

**Description:**  
Two horizontal M10 smooth rods spaced 50-80mm apart. A sled carriage rides on linear bearings between them. Single X-motor drives belt to move sled left-right. The entire X-assembly moves on Y-rails.

```
    [Y-Motor]═══════════════════[Y-Motor]
         ║     Y-smooth rods      ║
         ║                        ║
    [X-End]══════════════════[X-End]
         ║     X-smooth rods      ║
         ║       (60mm gap)       ║
         ║    ┌───────────┐       ║
         ║    │ THE PLOUGH│       ║
         ║    │ Pitan+V6  │       ║
         ║    └───────────┘       ║
```

**Pros:**
- Simple—one motor per axis, straightforward kinematics
- Extremely scavenger-friendly (any smooth rods, any bearings)
- Easy to understand, maintain, and repair
- Tolerant of frame imperfections (nuts adjust everything)
- Native Klipper support (simple `[stepper_x]` config)
- Direct lineage from Darwin → Mendel → Mendel i2
- M10 rods provide massive stiffness at 380mm span
- Pitan/V6 can be centered between rods (balanced)
- All components visible and accessible

**Cons:**
- Higher moving mass on Y-axis (entire X-assembly moves)
- Higher moving mass on X-axis (Plough + extruder + motor)
- Lower theoretical maximum speed than CoreXY
- X-motor rides on gantry (adds moving mass)

**Verdict:** Accepted—best fit for Neo-Darwin philosophy.

---

## Detailed Comparison Matrix

| Factor | Cross-Rod | CoreXY | The Plough |
|---|---|---|---|
| **Simplicity** | ⭐⭐ | ⭐⭐ | ⭐⭐⭐⭐⭐ |
| **Scavengeability** | ⭐⭐ | ⭐ | ⭐⭐⭐⭐⭐ |
| **Maintainability** | ⭐⭐⭐ | ⭐⭐ | ⭐⭐⭐⭐⭐ |
| **Frame Tolerance** | ⭐⭐⭐ | ⭐⭐ | ⭐⭐⭐⭐⭐ |
| **Klipper Config** | ⭐⭐⭐ | ⭐⭐⭐⭐ | ⭐⭐⭐⭐⭐ |
| **Max Speed** | ⭐⭐⭐⭐⭐ | ⭐⭐⭐⭐⭐ | ⭐⭐⭐ |
| **Moving Mass (X)** | ⭐⭐⭐⭐⭐ | ⭐⭐⭐⭐⭐ | ⭐⭐⭐ |
| **Moving Mass (Y)** | ⭐⭐⭐⭐⭐ | ⭐⭐⭐⭐⭐ | ⭐⭐ |
| **Rigidity** | ⭐⭐⭐⭐ | ⭐⭐⭐ | ⭐⭐⭐⭐⭐ |
| **Darwin Heritage** | ❌ | ❌ | ✅ |
| **Repairability** | ⭐⭐⭐ | ⭐⭐ | ⭐⭐⭐⭐⭐ |

---

## Why Moving Mass Penalty is Acceptable

### The M10 Advantage

At 380mm span with M10 smooth rods:
- Deflection under load is measured in microns
- Natural frequency is very high (won't resonate at print speeds)
- The "bounce" that plagues M8 systems doesn't exist

**The moving mass penalty of The Plough is almost irrelevant when rails don't flex.**

### Klipper Compensation

Klipper's Input Shaping can compensate for the higher moving mass:
- ADXL345 accelerometer measures actual resonance
- Software shapes motor commands to avoid exciting those frequencies
- Pressure Advance handles extruder response

**Result:** Quality prints at moderate speeds (150-250mm/s) with excellent surface finish.

### Quality Over Speed Philosophy

Neo-Darwin prioritizes:
1. Print quality (layer consistency, surface finish)
2. Reliability (prints complete successfully)
3. Repairability (fix it yourself)
4. Understanding (know how it works)

Speed is explicitly **not** a priority. A well-tuned Plough at 150mm/s produces better prints than a poorly-tuned CoreXY at 500mm/s.

---

## The Darwin Lineage

The Plough design maintains authentic RepRap heritage:

```
RepRap Darwin (2007)
    │
    ├── Box frame with threaded rods
    ├── Sled-style X-carriage
    └── Simple Cartesian kinematics
         │
         ▼
RepRap Mendel (2009)
    │
    ├── Triangular frame (still threaded rods)
    ├── Sled X-carriage between parallel rods
    └── Same kinematic philosophy
         │
         ▼
Mendel i2 (2012)
    │
    ├── Refined sled design
    ├── Better bearing arrangements
    └── Still threaded rod construction
         │
         ▼
Neo-Darwin (2025)
    │
    ├── M10 threaded rod frame (upgraded)
    ├── M10 smooth rod rails (upgraded)
    ├── "The Plough" sled (evolved)
    ├── Klipper brain (modernized)
    └── Same fundamental philosophy
```

**The Eustathios/HercuLien and CoreXY come from different branches:**

```
Ultimaker (2011)
    │
    └── Cross-rod / floating head
         │
         ▼
H-Bot → CoreXY (2012+)
    │
    └── Crossed belt systems
         │
         ▼
Eustathios / HercuLien (2014+)
    │
    └── Rod-based CoreXY variants
```

Neo-Darwin should remain true to its Darwin ancestry.

---

## The Plough: Design Specifications

### Rod Spacing

**60mm center-to-center (horizontal, top-down)**

Rationale:
- NEMA 17 motor is 42.3mm wide
- 4mm plastic walls on each side = 8mm
- ~10mm clearance for LM10UU housings
- Pitan/V6 nests perfectly between rods

### Bearing Arrangement

**LM10UU linear bearings with split-clamp housings**

- Minimum 2 bearings per rod (4 total)
- Spaced as far apart as carriage allows
- Split-clamp design (no zip ties)
- "Long wheelbase" prevents pitching during acceleration

### Extruder Positioning

**Pitan centered between rods, nozzle at geometric center**

- Weight balanced left-right
- No torque trying to twist carriage
- Belt attachment at carriage center (or balanced dual-attachment)

### Belt Path

**Single GT2 6mm belt, center-line routing**

- Belt runs parallel to X-rods
- Centered at 30mm mark (halfway between 60mm-spaced rods)
- Minimizes "cocking" force during acceleration

---

## Structural Optimization

### "Hollow Bone" Principle

The Plough should be designed with:
- 4-6 perimeter walls (not high infill)
- Structural ribs and webs
- Cut-away weight reduction where possible
- 3-5mm thick structural members

### Why Not Solid?

Solid plastic:
- Heavier (bad for moving mass)
- Cools unevenly (warps during printing)
- Wastes material

Ribbed structure:
- Lighter
- Cools evenly
- Looks "engineered"
- Actually stronger in bending

---

## Integration with Other Systems

### Dual Y-Steppers

The Plough design works perfectly with dual Y:
- Each Y-motor pulls one side of the X-assembly
- Klipper auto-squares on every home
- No mechanical coupling needed between Y-motors

### Triple Z with Kinematic Joints

Z-axis independence means:
- Plough doesn't need to compensate for bed tilt
- Klipper's `z_tilt_adjust` handles leveling
- X-gantry only needs to be parallel to itself

### Rubber Gasket Motor Isolation

X-motor on the Plough benefits from Strategy B sandwich mount:
- Reduces vibration transmitted to gantry
- Quieter operation
- Klipper Input Shaping handles residual resonance

---

## Rejected Optimizations

### Carbon Fiber X-Rods

**Considered:** Replacing M10 steel with CF tubes for weight reduction.

**Rejected:** 
- Not scavenger-friendly (must purchase)
- M10 steel is already stiff enough
- Adds complexity to bearing interface
- Against "hardware store" philosophy

### Pancake X-Motor

**Considered:** Using shorter NEMA 17 to reduce moving mass.

**Rejected:**
- Reduced torque
- May not be available from donor printer
- Standard NEMA 17 is fine for quality-focused printing

### Bowden Extruder

**Considered:** Moving extruder off gantry to reduce mass.

**Rejected:**
- Worse print quality (retraction tuning nightmare)
- Against quality-over-speed philosophy
- Direct drive is better for flexible filaments
- Pitan is the reference spec

---

## Future Upgrade Path

If users want more speed later, they can:

1. **Lighter Plough:** Redesign with more aggressive weight reduction
2. **Pancake Motor:** Swap X-motor for shorter variant
3. **Higher Acceleration:** Increase Klipper accel values
4. **Better Belts:** Upgrade to Gates GT3 belts

But the fundamental geometry—**sled on parallel rails**—scales well and doesn't need to change.

---

## Conclusion

The Parallel-Rail Sled ("The Plough") is the correct choice for Neo-Darwin because:

1. **It's simple** — One motor, one belt, two rods. Anyone can understand it.

2. **It's scavenger-friendly** — Photocopier rods, donor bearings, hardware store parts.

3. **It's maintainable** — All parts visible, accessible, replaceable with basic tools.

4. **It's authentic** — Direct descendant of RepRap Darwin and Mendel designs.

5. **It leverages M10** — The stiffness advantage negates the moving mass penalty.

6. **It prioritizes quality** — Reliable prints over maximum speed.

7. **It's a Tractor** — Heavy, reliable, fixable with a wrench.

**Neo-Darwin should feel like a machine tool, not a race car.**

---

## Decision Record

| Date | Decision | Rationale |
|---|---|---|
| 2025 | Selected Parallel-Rail Sled | Best fit for scavenger philosophy |
| 2025 | Rejected Cross-Rod | Too complex, wrong lineage |
| 2025 | Rejected CoreXY | Incompatible with threaded rod frame |
| 2025 | Set 60mm rod spacing | Optimal for Pitan nesting |
| 2025 | Specified split-clamp bearings | Better than zip-ties |
| 2025 | Confirmed center-line belt | Minimizes carriage twist |

---

## References

- RepRap Darwin (2007) — Original box-frame threaded rod printer
- RepRap Mendel (2009) — Triangular frame evolution
- Mendel i2 (2012) — Refined sled carriage
- Eustathios — Cross-rod gantry reference design
- HercuLien — Large-format cross-rod printer
- Ingentis — Modernized Cartesian sled design
- V-Core (early versions) — Rod-based Cartesian reference

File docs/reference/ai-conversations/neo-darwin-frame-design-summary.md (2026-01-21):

# Neo-Darwin "The Tractor" Frame Design Summary

A comprehensive summary of design decisions and recommendations for building a box-frame 3D printer using threaded rods, derived from iterative design discussions.

---

## 1. Design Philosophy

The Neo-Darwin (nicknamed "The Tractor") follows the **Scavenger Build** philosophy:

- Use readily available hardware from hardware stores (Bunnings) and salvaged components
- Bootstrap the build using a donor printer (Ender, Anet, i3 Mega) to print initial parts
- Prioritise repairability, adjustability, and accessibility over cutting-edge performance
- Target build volume: **235×235×235mm** (matching common heated bed sizes)

The design combines the repairability of the original Darwin/Mendel with modern performance through Klipper firmware integration.

---

## 2. Frame Rod Selection

### 2.1 Reference Specification: M10 Threaded Rod

**M10 is recommended as the reference specification** for the following reasons:

| Factor | M8 | M10 | M12 |
|---|-----|---|---|
| Cross-sectional area | ~50 mm² | ~78 mm² | ~113 mm² |
| Rigidity vs M8 | Baseline | ~1.5× stiffer | ~2.3× stiffer |
| Weight per metre | ~0.3 kg | ~0.5 kg | ~0.7 kg |
| Nut size (hex) | 13mm | 17mm | 19mm |
| Scavengeability | Common | Very common (automotive) | Less common |
| Bracket bulk | Compact | Moderate | Chunky |

### 2.2 Why M10 Over M12

- **Tooling**: 17mm wrench is nearly universal in household toolkits
- **Automotive abundance**: M10 is standard for suspension components, engine mounts, and seat rails—excellent for scavenging
- **Bracket design**: Allows for sleeker, more refined printed parts
- **Hardware availability**: Flanged M10 nuts are readily available and look professional
- **Sufficient stiffness**: For spans of 450-500mm, M10 provides more than adequate rigidity

### 2.3 When to Consider M12

- You want the absolute "tank" aesthetic
- Maximum mass damping is desired
- You already have M12 stock available
- Building a larger-than-reference machine

### 2.4 Parametric Design

The bracket design should be **parametric** in build123d:

```python
rod_type = "M10"  # User can change to "M8" or "M12"
params = {
    "M8":  {"dia": 8.5,  "nut_flat": 13, "sleeve_od": 22},
    "M10": {"dia": 10.5, "nut_flat": 17, "sleeve_od": 28},
    "M12": {"dia": 12.5, "nut_flat": 19, "sleeve_od": 32}
}
```

---

## 3. Frame Dimensions

### 3.1 Recommended Rod Lengths

For a 235×235mm bed with Triple-Z motors and direct-drive toolhead:

| Axis | Calculation | Recommended Length |
|---|---|---|
| X (Width) | Bed (235) + Lead screws/motors (80) + Clearance (65) | ~450mm |
| Y (Depth) | Bed (235) + Y-carriage travel (50) + Motor (60) | ~450mm |
| Z (Height) | Build height (280) + Motor/coupler (70) + Top bracket (50) | ~500mm |

> **Tip**: With the offset method, buy 1-metre rods and cut in half (500mm). Extra length isn't a problem—cap the ends with printed covers.

### 3.2 Frame Weight

With M10 rods:
- 12 rods (4 per axis) plus nuts and brackets
- Total frame weight: approximately **5-7 kg**
- This mass is beneficial—it absorbs ringing/ghosting caused by rapid direction changes

---

## 4. Squaring Strategy: The MDF Base-Anchor Method

This is the **critical innovation** that makes threaded-rod frames practical to build accurately.

### 4.1 The Core Principle

> *"If the base is square, and your brackets are printed well, the printer must be square."*

Instead of trying to square a wobbly skeleton of rods in mid-air, the MDF baseboard becomes a permanent **master reference jig**.

### 4.2 The MDF Base

**Specification:**
- Two layers of 18mm MDF laminated together = **36mm total thickness**
- Use PVA wood glue between the raw (unfinished) faces
- Clamp well and allow 24 hours to cure
- Pre-finished melamine shelving works well—the laminated faces provide a smooth, moisture-resistant surface

**Why laminated MDF works:**
- **Mass**: Heavy base lowers centre of gravity, prevents swaying during rapid accelerations
- **Damping**: MDF is internally "lossy"—converts vibration to heat rather than ringing
- **Flatness**: Factory surfaces are reliably flat
- **Moisture resistance**: Sealed surfaces prevent warping

**Sealing (optional but recommended):**
- Coat exposed MDF edges with diluted PVA glue to seal against humidity changes

### 4.3 The Squaring Workflow

#### Step 1: Mark the Master Layout

1. Draw a baseline near the front edge of the MDF
2. Draw two perpendicular lines going back (use a speed square or carpenter's square)
3. Draw the back line to complete the rectangle
4. **Critical check**: Measure both diagonals—they must be identical to the millimetre

#### Step 2: Mount the Base Anchors

1. Print four base anchor brackets
2. Place them precisely on the corners of your drawn rectangle
3. Drill through the MDF
4. Use M8 or M10 carriage bolts from underneath (counter-bored so bottom is flush)
5. Tighten anchors from above with large washers and nuts

**Result**: Four rigid plastic sockets fixed perfectly square to each other on an immovable base.

#### Step 3: Drop-In Assembly

1. **Verticals (Z)**: Slide M10 Z-rods into the vertical sockets—they will stand perfectly plumb (90° to the base)
2. **Horizontals (X & Y)**: Slide bottom X and Y rods through horizontal sockets—no measuring needed, just tighten nuts against anchors
3. **Top frame**: Slide top square onto pillars—it naturally falls into place

### 4.4 Squaring Verification

**The Diagonal Rule:**
- Measure from Front-Left to Back-Right
- Measure from Front-Right to Back-Left
- If these two measurements match, the frame is square

**Adjustment (if needed):**
- Slightly enlarge holes in MDF to "shift" an anchor bracket before final tightening

---

## 5. Corner Bracket Design

### 5.1 The Offset Method

Use the **Darwin/RepRap offset method** where rods bypass each other rather than meeting at a point:

```
Recommended layer order (outside to inside):
├── X-Rods (Left-to-Right): Outermost layer
├── Y-Rods (Front-to-Back): Middle layer
└── Z-Rods (Vertical): Innermost layer
```

**Why this order for Triple-Z:**
- Z-rods on the inside create a clear, unobstructed path for the build plate
- Horizontal rods don't block bed movement

### 5.2 Long Sleeve Design

The key to self-squaring brackets is **long sleeves** (50-60mm minimum):

**Benefits:**
- Rod physically cannot tilt within the sleeve
- Acts as a permanent squaring jig
- Eliminates need for separate squaring tools
- Provides massive grip area for the nut/washer interface

**Design features:**
- Sleeve length: 50-60mm minimum for Z-rods (the tall ones)
- Internal clearance: Rod diameter + 0.4-0.6mm (determined by calibration test)
- Optional internal alignment fins (0.2mm high ribs) to centre the rod

### 5.3 Base Anchor Bracket Requirements

The bottom four corners are different from the top—they must anchor to the MDF:

| Feature | Specification |
|---|---|
| Flange size | 80-100mm × 80-100mm |
| Flange thickness | 12-15mm |
| Bolt holes | 4× for M8 bolts in corners of flange |
| Z-rod passthrough | Through the flange so rod rests on MDF |
| Structural webbing | Fillets/gussets connecting sleeves to flange |

### 5.4 Nut and Washer Strategy

- Use **extra-thick fender washers** (large outer diameter) to distribute load
- Prevents high torque from crushing 3D-printed walls
- Consider **flanged nuts** (M10 flanged nuts have built-in washer)
- Use **Nyloc nuts** for final locking—won't vibrate loose

### 5.5 Wrench Access

Design "nut windows" into the brackets:
- Generous opening for 17mm spanner (M10) or 19mm (M12)
- Consider access from multiple angles

---

## 6. X-Gantry Design

### 6.1 Motion System Overview

The Neo-Darwin uses a **Z-dropdown** configuration:
- Bed moves only vertically (Z-axis) on Triple-Z lead screws
- X-Y gantry moves at the top of the frame
- Similar to CoreXY/Voron layout but using the "Tractor" frame

### 6.2 X-Carriage: "The Plough"

The X-carriage design follows the Mendel i2 "plough" style, updated for M10 rods.

**Reference design**: [Thingiverse Thing:3940673](https://www.thingiverse.com/thing:3940673)

**Key modifications needed:**
- Replace zip-tie bearing mounts with **split-clamp housings**
- Add structural cut-aways (more walls, less infill)
- Accommodate Pitan/Titan direct-drive extruder with E3D V6 hotend

### 6.3 Smooth Rod Spacing for X-Gantry

For the "top-down" plough configuration where the **Pitan nests between the rods**:

| Configuration | Spacing (C-to-C) | Notes |
|---|---|---|
| Vertical stack | 50mm | Rods stacked vertically |
| **Top-down/horizontal** | **58-62mm** | Pitan nested between rods (recommended) |

**60mm spacing calculation:**
- NEMA 17 motor width: 42.3mm
- Structural wall thickness: 4mm × 2 sides = 8mm
- LM10UU bearing clearance: ~10mm
- **Total: ~60mm**

### 6.4 Bearing Mounts: Split-Clamp Design

Replace zip-ties with proper clamped bearing housings:

```python
# Conceptual split-clamp for LM10UU
bearing_od = 19.0 + 0.2  # Nominal + slop
bearing_len = 29.0
clamp_bolt_dia = 3.5     # For M3 pinch bolt

# Design features:
# - C-shaped housing around bearing
# - M3/M4 bolt pinches housing closed
# - Zero slop, serviceable, adjustable preload
```

**Advantages:**
- Accounts for print inaccuracies from donor printer
- Bearings can be swapped without breaking carriage
- Tightening bolt slightly deforms plastic for perfect grip

### 6.5 Structural Optimisation

For maximum strength with minimum weight:

- **4-6 perimeter walls** provide more rigidity than solid infill
- Use **structural ribs/webbing** instead of solid blocks
- Cut-away pockets leave 3-5mm thick structural beams
- Ribs help break up resonance frequencies from stepper motors

---

## 7. Z-Axis: Triple-Z with Kinematic Joints

### 7.1 Configuration

- **Three lead screws** in a triangle pattern:
  - Two at front corners
  - One at centre-back
- Creates a stable tripod that defines a perfect plane
- Klipper's `z_tilt_adjust` automatically levels the bed

### 7.2 The Kinematic Z-Joint

**Problem**: If three Z-rods aren't perfectly parallel, a rigid bed mount will bind, skip steps, and leave print artifacts.

**Solution**: Decouple the lead screw (movement) from the smooth rod (constraint).

#### The "Ball and Cup" Design (Scavenger's GE5C)

Instead of buying GE5C spherical bearings:

1. **Nut carrier**: T8 lead screw nut bolted to a small printed part
2. **Ball**: 6mm or 8mm steel ball (from a large bearing) sits on the carrier
3. **Bed bracket**: Has a conical "cup" that rests on the ball
4. **Gravity holds it down**—if the lead screw tilts, the ball shifts in the cup without bending anything

#### The "Two-Part" Bracket

- **Smooth rod side (rigid)**: Houses LM8UU/LM10UU, bolted to bed, maintains X-Y position
- **Lead screw side (floating)**: T8 nut in an oversized pocket, can move laterally but not vertically

### 7.3 Mixing Rod Sizes

If using M8 smooth rods from an i3 Mega donor with M10 threaded frame:

- Z-guides: M8 smooth rods (scavenged)
- Frame: M10 threaded rod (purchased)
- Corner anchors need: 10.5mm hole for frame, 8.2mm hole for Z-rod

> **Note**: M8 rods are thinner and may flex more—the kinematic joints and triple-Z configuration compensate for this.

---

## 8. Motion System: Dual-Y Gantry Drive

### 8.1 Why Dual-Y Motors

For a Z-dropdown gantry design:

- **One NEMA 17 at back-left, one at back-right**
- Prevents cantilever lag at rod ends
- Each side driven independently = no racking or twisting
- Klipper handles synchronisation seamlessly

### 8.2 Automatic Squaring

With dual Y-motors on separate drivers:

1. Place one endstop on left Y-rail, one on right Y-rail
2. When printer homes, each motor moves until it hits its own switch
3. **Gantry automatically squares to frame every power-on**

Klipper configuration:
```ini
[stepper_y]
# Left side motor config

[stepper_y1]
# Right side motor config
```

### 8.3 Belt Tensioning

Design motor mounts with **slots** (not holes) for motor bolts:
- 8mm long slots allow sliding motor to tension belt
- Eliminates need for separate tensioner at front

---

## 9. Electronics and Motors

### 9.1 Motor Requirements

| Axis | Quantity | Notes |
|---|---|---|
| X | 1 | Use lightest motor (travels on gantry) |
| Y | 2 | Use matched pair from same donor |
| Z | 3 | Use identical motors if possible |
| E | 1 | Standard extruder motor |
| **Total** | **7** | |

### 9.2 Sourcing Strategy

**Option A: Double Donor** (recommended for scavenger builds)
- Two Ender/Anet/i3 Mega donors provide 8 motors
- Also get: second PSU, endstops, cables, smooth rods, electronics

**Option B: Single Donor + Purchase**
- One donor provides 4 motors
- Purchase 3 additional NEMA 17s

### 9.3 Multi-MCU Klipper Configuration

With two donor mainboards:

```ini
[mcu]
serial: /dev/serial/by-id/usb-board_1

[mcu aux]
serial: /dev/serial/by-id/usb-board_2
```

**Suggested allocation:**
- Board 1: X, Y1, Y2, E
- Board 2: Z1, Z2, Z3

Klipper handles microsecond synchronisation—feels like one 7-driver board.

### 9.4 Power Supply Considerations

With 7 motors and a large heated bed, a single 250-350W PSU may be insufficient.

**Two-PSU strategy:**
- PSU 1: Motherboard + X/Y/E motors
- PSU 2: 3×Z motors + heated bed
- **Critical**: Connect V- (negative) terminals together for common ground

---

## 10. Calibration and Assembly

### 10.1 The "Lumpy Gauge" Calibration Test

Before printing full brackets, print a calibration slug to find your donor printer's optimal clearance:

```python
# Test three hole sizes
test_offsets = [0.2, 0.4, 0.6]  # Added to nominal diameter

# For M10: test 10.2mm, 10.4mm, 10.6mm holes
# For M10 nut (17mm): test 17.2mm, 17.4mm, 17.6mm hex traps
```

**Testing procedure:**
1. **Push test**: Find hole where rod slides through with firm push but doesn't wiggle
2. **Drop test**: Find hex trap where nut drops in but doesn't spin under torque
3. Use those offsets in final bracket design

### 10.2 Donor Printer Preparation

Before printing Tractor parts:

1. **Paper test**: Ensure bed is level
2. **Belt tension**: Tighten belts (loose belts cause "racking")
3. **Square test**: Print 100×100mm L-shape (2mm thick), check against a square

### 10.3 Print Settings for Structural Parts

| Setting | Value | Reason |
|---|---|---|
| Infill | 40%+ | Compression strength for nuts |
| Walls/Perimeters | 5-6 | Sleeve strength comes from walls |
| Material | PLA or PETG | Whatever donor prints reliably |
| Layer height | 0.2mm | Balance of speed and strength |

### 10.4 Cutting Hardened Smooth Rods

Photocopier rods are often **induction hardened**:

- Hacksaw blades will skate off and go blunt
- **Use**: Angle grinder with thin (1mm) Inox cutting disc
- **Alternative**: Dremel with reinforced cutoff wheel
- **Hacksaw hack**: Grind through hardened "skin" first, then saw soft core
- **Always wear eye protection**

---

## 11. Software Configuration

### 11.1 Klipper Features to Utilise

| Feature | Purpose |
|---|---|
| `[z_tilt]` | Auto-level Triple-Z bed using 3 probe points |
| `[stepper_y1]` | Dual Y-motor with independent homing |
| Input Shaping | Compensate for any residual resonance |
| Pressure Advance | Optimise extrusion for speed |

### 11.2 Expected Performance

With the massive MDF base and M10 frame:
- Very high, clean resonance frequencies
- Input Shaping calibration will be highly effective
- Minimal low-frequency wobbles
- **Exceptionally quiet operation**—frame doesn't act as speaker cone

---

## 12. Summary: The Tractor Reference Specification

| Component | Specification |
|---|---|
| Frame rods | M10 threaded (parametric for M8/M12) |
| Frame dimensions | 450×450×500mm (rod lengths) |
| Base | 36mm laminated MDF (2×18mm) |
| Squaring method | MDF base-anchor with long-sleeve brackets |
| X smooth rods | M10 (scavenged from photocopiers) |
| X-rod spacing | 60mm centre-to-centre (horizontal/top-down) |
| Z smooth rods | M8 or M10 (from donor or scavenged) |
| Z configuration | Triple-Z with kinematic joints |
| Y drive | Dual motors with dual endstops |
| Motors required | 7 total (1X, 2Y, 3Z, 1E) |
| Electronics | Dual-MCU Klipper configuration |
| Extruder | Pitan/Titan direct drive with E3D V6 |

---

## 13. Next Steps

1. **Print calibration gauge** on donor printer to determine slop factors
2. **Source materials**: M10 threaded rod, MDF sheets, hardware
3. **Design base anchors** in build123d with determined tolerances
4. **Laminate and mark MDF base**
5. **Print and mount base anchors**
6. **Assemble frame** using drop-in method
7. **Verify squareness** with diagonal measurements
8. **Continue with gantry and Z-axis assembly**

---

*Document generated from Neo-Darwin design discussions. Design philosophy: "A Tractor with the Brain of a Racecar"—heavy, reliable hardware with modern Klipper firmware.*

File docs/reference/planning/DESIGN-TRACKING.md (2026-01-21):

# Phase 2: Design Tracking

## Design Checklist

### Foundation: Frame Geometry
- [x] Expand config.py with frame parameters
- [x] Finalize frame parts count (9 parts)
- [x] Document Z-system geometry
- [x] Document Z-Tilt leveling process

### Corner Bracket Designs
- [x] Corner 1: Front-Left (Z-mount integrated) ✅ DESIGNED
  - [x] M12 vertical rod clamp (front L)
  - [x] M12 horizontal rod clamp (front L)
  - [x] M12 vertical rod clamp (front C-L)
  - [x] Integrated Z1 motor mount
  - [x] Leadscrew path clearance (vertical)
  - [x] Cable routing channels
  - [x] Jam nut access points
  - [ ] Render in VSCode - VSCode shows errors for old code
  - [ ] Verify geometry
  - File: cad/parts/corner_1_front_left_z1.py

- [ ] Corner 2: Front-Right (Z-mount integrated)
  - [ ] M12 vertical rod clamp (front R)
  - [ ] M12 horizontal rod clamp (front R)
  - [ ] M12 vertical rod clamp (front C-R)
  - [ ] Integrated Z2 motor mount
  - [ ] Leadscrew path clearance (vertical)
  - [ ] Cable routing channels
  - [ ] Jam nut access points
  - [ ] Render in VSCode
  - [ ] Verify geometry

- [ ] Corner 3: Back-Left (standard)
  - [ ] M12 vertical rod clamp (back L)
  - [ ] M12 horizontal rod clamp (back L)
  - [ ] M12 vertical rod clamp (back C-L)
  - [ ] No Z-motor mount
  - [ ] Reinforcement structure
  - [ ] Jam nut access points
  - [ ] Render in VSCode
  - [ ] Verify geometry

- [ ] Corner 4: Back-Right (standard)
  - [ ] M12 vertical rod clamp (back R)
  - [ ] M12 horizontal rod clamp (back R)
  - [ ] M12 vertical rod clamp (back C-R)
  - [ ] No Z-motor mount
  - [ ] Reinforcement structure
  - [ ] Jam nut access points
  - [ ] Render in VSCode
  - [ ] Verify geometry

### Z-Puck Design
- [ ] Z-puck: Back-Center (on bottom horizontal rod)
  - [ ] M12 horizontal rod clamp
  - [ ] Integrated Z3 motor mount
  - [ ] Leadscrew path clearance (vertical)
  - [ ] Leadscrew nut trap
  - [ ] Cable routing to bottom
  - [ ] Slide mechanism (if adjustable height)
  - [ ] Render in VSCode
  - [ ] Verify geometry

### Spider Bed Support
- [ ] Spider Hub (center)
  - [ ] Triangle shape (equilateral, 120mm)
  - [ ] 3 arm mounting points (40mm spacing)
  - [ ] Interlocking design
  - [ ] Cable routing cutout
  - [ ] Render in VSCode
  - [ ] Verify geometry

- [ ] Spider Arms (3x)
  - [ ] Trapezoid shape (150mm length)
  - [ ] Bed mounting points (2 bolts per arm)
  - [ ] Leadscrew nut trap
  - [ ] Interlock with hub
  - [ ] Render in VSCode
  - [ ] Verify geometry

### Gantry (Top Frame)
- [ ] Corner TL: Top-Left (standard)
  - [ ] M12 vertical rod clamp (top L)
  - [ ] M12 horizontal rod clamp (top L)
  - [ ] Smooth rod mounting
  - [ ] Render in VSCode
  - [ ] Verify geometry

- [ ] Corner TR: Top-Right (standard)
  - [ ] M12 vertical rod clamp (top R)
  - [ ] M12 horizontal rod clamp (top R)
  - [ ] Smooth rod mounting
  - [ ] Render in VSCode
  - [ ] Verify geometry

- [ ] Corner BL: Bottom-Left (standard)
  - [ ] M12 vertical rod clamp (bottom L)
  - [ ] M12 horizontal rod clamp (bottom L)
  - [ ] Smooth rod mounting
  - [ ] Render in VSCode
  - [ ] Verify geometry

- [ ] Corner BR: Bottom-Right (standard)
  - [ ] M12 vertical rod clamp (bottom R)
  - [ ] M12 horizontal rod clamp (bottom R)
  - [ ] Smooth rod mounting
  - [ ] Render in VSCode
  - [ ] Verify geometry

### Motion System
- [ ] X-carriage
  - [ ] Bearing clamps (4x LM10UU)
  - [ ] Extruder Puck base
  - [ ] Wade extruder mounting
  - [ ] BLTouch/PINDA mount
  - [ ] Render in VSCode
  - [ ] Verify geometry

- [ ] Y-gantry brackets
  - [ ] Dual smooth rod support
  - [ ] Bearing clamps (8x LM10UU)
  - [ ] Motor mounts (X and Y)
  - [ ] Render in VSCode
  - [ ] Verify geometry

### Extruder
- [ ] Wade Main Body
- [ ] Wade Motor Mount
- [ ] Wade Idler Arm
- [ ] Wade Idler Tensioner
- [ ] Wade Gears (pinion + 47-tooth)
- [ ] Extruder Puck Adapter

### Electronics
- [ ] Brain Puck
  - [ ] MKS SKIPR mount pattern
  - [ ] Cable routing
  - [ ] Fan mounting (if needed)
  - [ ] Render in VSCode
  - [ ] Verify geometry

---

## Design Workflow

### For Each Part:
1. **Read config.py** for parameters
2. **Write build123d code** in `cad/parts/` directory
3. **Import config** values into part design
4. **Render in VSCode** using build123d extension
5. **Verify geometry**:
   - Check dimensions match config
   - Check for collisions
   - Check clearance
6. **Report back**:
   - "Part renders correctly, ready for next"
   - OR "Issue: need to adjust X by Ymm"
7. **Iterate** if needed

---

## Starting Point: Corner 1 (Front-Left + Z1)

### Parameters from config.py:
```
M12_FIT_DIA = 12.5  # 12.0 + 0.5 lumpy factor
X_OVERHANG = 50.0  # Wade overhang
CORNER_TYPE = "Z_MOUNT_INTEGRATED"
```

### Design Requirements:
- 4x M12 rod clamps (vertical L, vertical C-L, horizontal L, horizontal front C-L)
- Z1 NEMA17 motor mount
- Motor bolt pattern: NEMA17 standard
- Leadscrew clearance: Vertical path through frame
- Jam nut access: Easy access to all 4 clamps
- Cable routing: Channel for motor wires
- Wall thickness: 4-5mm
- Infill: 40-50%
- Material: PETG or ABS

---

## Current Status

**Phase 2 Active**: Designing corner brackets

**Working on**: Corner 1 (Front-Left + Z1 integrated)

**Next**: After Corner 1 complete → Corner 2 (Front-Right + Z2)

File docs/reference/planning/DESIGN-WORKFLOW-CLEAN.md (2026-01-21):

# Phase 2: Clean Design Workflow (No venv required)

## User Clarification

**User only uses VSCode as STL viewer, not for running code.**

So:
- VSCode import errors are ANNOYING but NOT blocking
- Just need part files to generate clean STL exports
- No need for venv or complex setup

---

## Simplified Design Workflow

### For Each Part:

1. **Write part code** in `cad/parts/`
   - Import from config.py
   - Use build123d directly
   - Write clean, self-contained code

2. **Generate STL**
   ```bash
   python cad/parts/your_part.py
   ```
   - STL automatically exports to `cad/stl/`

3. **View in VSCode** (build123d extension)
   - Open `cad/stl/your_part.stl`
   - Check dimensions
   - Verify geometry
   - Adjust if needed

4. **Iterate**
   - Edit part code
   - Regenerate STL
   - Verify again

---

## Current Status

✅ **Corner 1 (Front-Left + Z1)**: Designed
- File: `cad/parts/corner_1_front_left_z1.py`
- Ready to generate STL

---

## VSCode Notes

### Import Errors Are Expected
- VSCode tries to lint old code (`main.py`, `components/*.py`)
- These imports will fail (files/modules don't exist)
- **Ignore these errors** - they don't affect new part generation
- Only `cad/parts/` has clean, working code

### What Matters
- Can you open the STL file in VSCode?
- Can you verify dimensions look correct?
- Did the STL export successfully?

### Disable VSCode Linting for Old Files (Optional)

**Create `.vscode/settings.json`:**
```json
{
  "python.linting.ignorePatterns": [
    "cad/main.py",
    "cad/components/*.py",
    "cad/project_vars.py",
    "cad/parts/corners.py",
    "cad/parts/z_pucks.py",
    "cad/parts/carriage.py",
    "cad/parts/electronics.py"
  ]
}
```

**Result:** VSCode won't try to lint old code, focus only on new parts/

---

## Quick Start

### Generate Corner 1 STL:

```bash
cd /Users/michael/Projects/Personal/neo-darwin
python cad/parts/corner_1_front_left_z1.py
```

### Check in VSCode:
1. Open `cad/stl/corner_1_front_left_z1.stl`
2. Use build123d extension viewer
3. Verify dimensions:
   - M12 rod diameter: 12.5mm
   - Motor mount: 42×42mm NEMA17
   - Rod clamps: 4 positions
4. Adjust code if needed

### Continue Workflow:
- ✅ Corner 1 designed
- [ ] Corner 2 (Front-Right + Z2)
- [ ] Corner 3 (Back-Left)
- [ ] Corner 4 (Back-Right)
- [ ] Z-puck (Back-Center)
- [ ] Spider bed support
- [ ] Top corners (TL, TR, BL, BR)
- [ ] X-carriage
- [ ] Y-gantry
- [ ] Wade extruder
- [ ] Electronics

---

## config.py Status

Current `cad/config.py` is basic (46 lines).

For Phase 2, you can:
1. Keep using basic config.py (it works!)
2. Add parameters in individual part files as needed
3. OR expand config.py gradually with new parameters

**Recommendation:** Keep config.py simple, add what you need directly in part files.

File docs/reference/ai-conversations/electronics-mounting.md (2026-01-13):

This is a solid engineering choice for a custom high-quality build. Mounting the electronics to a baseboard rather than the printer frame itself is a technique often used in high-end DIY builds (like Vorons or custom "RatRig" styles) to isolate delicate electronics from mechanical vibrations.

### 1. The MDF "Mass-Loaded" Base

Mounting the M12 frame to a heavy piece of **MDF (Medium Density Fibreboard)** is an excellent way to add "damping mass."

* **Vibration Absorption:** MDF is much more "dead" (acoustically and mechanically) than plywood or solid timber. It will act as a sink for the vibrations generated by the high-torque Wade's extruder.
* **Rigidity:** Use a thick sheet ( or ). If the base is rigid, the M12 rods won't be able to "twist" the frame relative to the surface it's sitting on.
* **Tip:** Seal the MDF with a quick coat of paint or sealer. Bare MDF can absorb moisture over time, which might cause it to warp and throw off your frame's squareness.

### 2. Honeycomb Electronics Box

An open honeycomb design is perfect for your goals. Since your printer is a "bed-down" Cartesian (where the XY gantry stays at the top and the bed moves down), placing the electronics in the bottom square is very safe.

* **Airflow:** Even without a fan, the large surface area of a honeycomb mesh allows for natural convection. However, because you're using high-torque motors, your stepper drivers (like TMC2209s) will get hot. I'd still recommend one slow, large () "silent" fan blowing over the board.
* **Debris Protection:** While the bed moves down, it won't hit the electronics, but **bits of filament or plastic "poops"** can fall through. I suggest a "lid" for your honeycomb box that is solid, while the sides remain honeycomb.

### 3. The "Wiring Loom" Challenge

Moving the electronics to the base means your wires have to travel further. This is the biggest hurdle for this layout:

* **Voltage Drop:** For the heated bed (which draws the most current), use **thick gauge wire** ( or  AWG). Long, thin wires will get hot and cause the bed to heat up slowly.
* **Cable Chains:** Since your X and Y axes are at the top, you'll need a long "umbilical" cord. A 3D-printed drag chain (cable chain) is the best way to keep this looking professional and prevent wires from snagging on the moving bed.
* **Signal Interference:** Keep your endstop and probe wires away from the high-voltage motor and bed wires to prevent "ghost" triggers caused by electromagnetic interference (EMI).

---

### Suggested Layout Design

### Final Component Checklist for <$300 AUD:

| Component | Scavenge or Buy? | Est. Cost (AUD) |
| --- | --- | --- |
| **Frame** | M12 Rods + Nuts/Washers | ~$60 (Hardware store) |
| **Motors** | Scavenge from Bed Slinger | $0 |
| **Board** | BTT SKR Pico or E3 V3 | ~$50–$70 |
| **MDF Base** | 18mm Sheet | ~$30 (Bunnings) |
| **Triple Z** | 2 Extra Steppers + Lead Screws | ~$60 |
| **Wade's Extruder** | Print parts + Buy Gears/Bolts | ~$20 |
| **Cabling** | 10m various gauge wire | ~$30 |

**Total Estimated:** ~$270 AUD (leaving you $30 for a meat pie and some extra zip ties).

**Since you're using Triple Z motors, would you like me to explain how to wire them?** (You can either wire them in series to one driver or use a board with enough independent drivers to auto-level the bed).

Establishing your intent: You are refining the **Electronics & PSU mounting strategy** for the Neo-Darwin. You want to compare mounting directly to the **Laminated MDF Plinth** (Reference Spec) versus a **printed standalone frame** (Modular Puck) that sits inside the bottom square, especially regarding vibration isolation and the role of rubber pads.

### 1. Mounting to the Baseboard vs. Printed Frame

The choice between these two methods depends on whether you prioritize **Massive Damping** or **Modular Portability**.

* **The Reference Spec (Mounting to MDF Plinth):**
* **Logic:** Mounting the electronics (Mainboard, RPi) and the PSU directly to the laminated MDF baseboard is the most "industrial" solution.
* **Vibration Sink:** The MDF plinth acts as a massive "vibration sink." By bolting the PSU and MCU to this bedrock, you ensure they are not vibrating in sympathy with the frame’s motion.
* **Heat Management:** A large MDF board provides more surface area and airflow "headroom" within the bottom square compared to a cramped printed enclosure.

* **The Alternative (Printed "Brain Puck" Frame):**
* **Logic:** For users without an MDF base plate, you provide a printed "Puck" or frame that holds the electronics. This "Brain Puck" sits on the same surface as the M12 frame, connected only by the wiring loom.
* **Benefit:** This is excellent for **portability** and **Tier 1/2 builders** who may want to pull the entire electronics suite out for maintenance without unbolting the printer frame.
* **Downside:** Because it is lightweight plastic, it does not have the "inertial authority" of the MDF board. It may move or vibrate slightly if not secured to the workbench.

---

### 2. The Physics of Vibration: Bolting "Through" Rubber Pads

You asked if bolting the frame *through* the rubber pads into the MDF is better than bolting the frame directly to the board. This is a common point of confusion in vibration physics.

* **Isolation vs. Coupling:**
* **Direct Bolting (Coupling):** If you bolt the M12 frame directly to the MDF, you are "coupling" them. The frame's vibration is instantly shared with the MDF’s mass. Because the MDF is laminated and heavy, it kills the vibration quickly (Constrained Layer Damping).
* **Bolting Through Rubber (Isolation):** If you place rubber between the frame and the board and then bolt *through* it, you create a "tuned mass damper."

* **The Recommendation:** * For a **"Tractor" build**, **Direct Coupling** to the MDF is often preferred for the frame. You want the frame to be as rigid as possible to the baseboard so they act as one single, immovable object.
* Use the **Rubber Pads** underneath the **MDF Plinth** itself. This isolates the entire 20kg+ machine from your desk, preventing the desk from becoming a sounding board.

---

### 3. Is the "Standalone Frame" better?

Is building a separate frame for electronics and placing it inside the base square "even better" than mounting to the board?

* **Engineering Verdict:** It is **better for serviceability**, but **worse for vibration.**
* **The Hybrid Approach:** The best "Neo-Darwin" solution is to mount the electronics to a **Printed "Puck"** first, and then **screw that Puck into the MDF baseboard**.
* This gives you the best of both worlds: you get the industrial damping of the MDF and the modular "Puck" system that allows for easy hardware swaps if you upgrade your mainboard later.

| Feature | Mounted to MDF (Reference) | Standalone Printed Frame |
| --- | --- | --- |
| **Vibration Damping** | **Superior** (Uses Plinth mass) | Poor (Relies on plastic mass) |
| **Maintenance** | Permanent (Harder to remove) | **Excellent** (Can be moved) |
| **Cost** | Minimal (Screws) | Moderate (Filament/Time) |
| **Airflow** | Open and clean | Can be restricted if enclosed |

**"The iron provides the squareness; the MDF provides the silence; the Puck provides the modularity."**

**Would you like me to draft the specific "Electronics Puck" assembly instructions for the manual?**

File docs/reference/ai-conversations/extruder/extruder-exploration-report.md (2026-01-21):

# Neo-Darwin Extruder Exploration Report
## A Comprehensive Analysis of Extruder Options and Final Recommendation

---

## Executive Summary

This report documents the exhaustive exploration of extruder options for the Neo-Darwin 3D printer project, following the "Tractor with the Brain of a Racecar" philosophy. After evaluating weight, cost, scavengability, mechanical performance, and compatibility with Klipper, the **Pitan Extruder** has been selected as the reference standard.

**Key Finding:** Modern extruders like the Bambu Lab X1C prove that a well-tuned single direct-drive extruder can achieve superior print quality through software intelligence rather than raw mechanical complexity. The Pitan embodies this approach - lightweight, direct-drive, and perfectly suited to a Klipper-controlled "Tractor" that prioritizes quality over speed.

---

## Project Context and Philosophy

### The "Tractor" Philosophy

The Neo-Darwin project is built around these core principles:

1. **High-Mass Foundation:** M12 threaded rod frame provides mechanical stability and vibration damping
2. **Scavengable Parts:** Components should be obtainable from donor printers, office equipment, or hardware stores
3. **Quality Over Speed:** Inspired by Bambu Lab X1C demonstrating that single-drive + Klipper > dual-drive speed for quality
4. **Klipper Intelligence:** Use software to compensate for mechanical limitations rather than over-engineering hardware
5. **Budget-Conscious:** Target $300 AUD build cost while maintaining MK4-quality output

### The Material Requirements

The Neo-Darwin is designed primarily for:
- **PLA & PLA+:** Most common hobbyist filament
- **PETG:** Functional prints and improved durability
- **TPU:** Flexible materials (requires direct drive for best results)

Exotic materials requiring enclosed, heated chambers are **not** a priority, as the open M12 frame makes enclosure impractical. This focus aligns with 95% of hobbyist use cases.

---

## The Extruder Evaluation Criteria

Each extruder option was evaluated against these criteria:

| Criterion | Weight | Description |
|---|---|---|
| **Weight** | Critical | Direct-drive weight affects gantry sag on M8/M10 rods |
| **Cost** | High | Must fit scavenger-friendly budget |
| **Scavengability** | High | Can parts be sourced from donor machines? |
| **Print Quality** | High | Consistent extrusion for PLA/PETG/TPU |
| **Repairability** | High | Can machine print its own replacement parts? |
| **Torque** | Medium | Sufficient for common filaments, not racing |
| **Complexity** | Low | Fewer failure points = better reliability |

---

## Extruder Options Explored

### 1. Greg's Wade Geared Extruder (Classic RepRap)

#### Overview
The Greg's Wade is the "Flat-6 Engine" of the 3D printing world - mechanical, geared, and visibly functional. Originally designed in the RepRap era (2007-2009), it represents pure DIY heritage.

#### Specifications
| Attribute | Value |
|---|---|
| Gear Ratio | 3.3:1 (43:13 teeth) |
| Motor | Full NEMA17 |
| Weight | 450-600g (with motor) |
| Drive Mechanism | Single hobb gear |
| Push Force | High (7.4N) |

#### Pros
- **Massive Torque:** 3.3:1 gear reduction provides "unstoppable" extrusion force
- **Zero Proprietary Parts:** Uses M8 bolts, 608 skate bearings, and printed gears
- **Full Repairability:** Can print replacement gears in 50 cents of filament
- **RepRap Heritage:** Pure DIY spirit, visually mechanical
- **Heat Creep Resistance:** Large distance between motor and hotend

#### Cons
- **Excessive Weight:** 450-600g causes significant gantry sag on M8 rods, marginal on M10
- **Mounting Complexity:** Old designs use long through-bolts; difficult to retrofit sensors
- **Inertia Penalty:** Heavy mass causes ringing/direction-change artifacts
- **Requires M10 Rods:** For 200×200+ build volume, M8 rods inadequate
- **Limited TPU Performance:** Single-gear drive struggles with flexible filaments

#### Engineering Analysis

**Rod Sag Calculations (from extruder.md):**
- M8 rods @ 250mm span with Wade: ~0.09mm sag (borderline)
- M10 rods @ 250mm span with Wade: ~0.019mm sag (acceptable)
- **Conclusion:** Wade forces M10 rods requirement for reliability

**Compatibility with Neo-Darwin:**
The Wade extruder conflicts with the scavenger-friendly approach because:
1. Forces upgrade from scavenged M8 rods (common in Ender 3 donors)
2. Requires stiffer gantry design
3. Limits build volume or demands mechanical supports

**Verdict: ❌ Not Recommended for Reference Spec**

---

### 2. Sherpa Mini (Modern Lightweight)

#### Overview
Developed by Annex Engineering, the Sherpa Mini has become the de facto standard for lightweight direct-drive extruders. It uses BMG clone gears in a compact, dual-drive configuration.

#### Specifications
| Attribute | Value |
|---|---|
| Gear Ratio | 5:1 (50:10) or 6.25:1 (50:8) |
| Motor | Round NEMA14 pancake (integrated pinion) |
| Weight | 110-127g (complete) |
| Drive Gears | BMG clone (dual drive) |
| Push Force | 120-180N |

#### Pros
- **Extremely Light:** ~120g total - no gantry sag issues
- **BMG Ubiquity:** Gears cost $3-8 and available everywhere
- **Massive Community:** Years of documentation, PDF assembly manual, active Discord
- **Dual-Drive:** Excellent TPU performance
- **Sherpa Mount Standard:** Compatible with most toolhead designs
- **Battle-Tested:** Thousands in service worldwide

#### Cons
- **Proprietary Gears:** Requires BMG clone kit (not pure hardware store)
- **Heat-Set Inserts:** Assembly requires soldering iron for insert installation
- **Gear Mesh Adjustment:** Can be fiddly to optimize
- **Clone Quality Variation:** BMG gear quality varies by vendor

#### Engineering Analysis

**Rod Sag Calculations (from extruder.md):**
- M8 rods @ 250mm span with Sherpa (NEMA14): ~0.015mm sag (excellent)
- M8 rods @ 250mm span with Sherpa (NEMA17): ~0.034mm sag (good)
- **Conclusion:** Sherpa enables M8 rods to work reliably

**Cost Breakdown (from neo-darwin-extruder-options.md):**
- BMG clone gear set: $3-8 AUD
- Round NEMA14 pancake motor: $10-15 AUD
- Hardware/inserts/PTFE: ~$5 AUD
- **Total:** ~$18-28 AUD

**Scavenger Analysis:**
The Sherpa Mini requires specific purchased components:
1. Round NEMA14 pancake motor with integrated pinion (not common in old printers)
2. BMG clone gears (must be purchased)

However, it enables the use of scavenged M8 rods, which offsets the motor/gear cost.

**Verdict: ⭐ Strong Contender, Recommended Alternative**

---

### 3. ProtoXtruder

#### Overview
Designed by nhchiu, the ProtoXtruder uses HGX-lite gear kits with larger 18mm diameter drive gears. Offers simpler assembly than Sherpa but uses less common parts.

#### Specifications
| Attribute | Value |
|---|---|
| Gear Ratio | 5:1 |
| Motor | Round NEMA14 pancake |
| Weight | ~125g |
| Drive Gears | HGX-lite (18mm diameter) |

#### Pros
- **Simpler Build:** Fewer parts, ~1 hour print time
- **Larger Drive Gears:** 18mm diameter provides better grip
- **All-in-One Kit:** HGX-lite includes everything needed
- **Sherpa Compatible:** Uses same mounting pattern

#### Cons
- **Higher Gear Cost:** HGX-lite kits $8-16 vs $3-8 for BMG
- **Less Common:** Harder to source spares
- **Limited Support:** Newer design, fewer community resources
- **Less Documentation:** GitHub README only, no assembly manual

**Verdict: ⚠️ Viable Alternative, but Sherpa Preferred**

---

### 4. BMG Clone Complete (Heavy)

#### Overview
Pre-assembled BMG clone extruders with full NEMA17 motors, sold as complete units. No printing required.

#### Specifications
| Attribute | Value |
|---|---|
| Gear Ratio | 3:1 |
| Motor | Full NEMA17 |
| Weight | 250-350g |

#### Why Not Recommended
| Issue | Impact |
|---|---|
| Weight | 250-350g causes gantry sag on bed-slinger designs |
| Gantry Sag | Mechanical issues on M8/M10 rods |
| Not RepRap | No printed parts, no customization possible |
| Motor Waste | Uses full NEMA17 better suited for Z axis |
| Bowden-Optimized | Performs best as bowden, not direct drive |

**Verdict: ❌ Not Recommended**

---

### 5. Voron M4 / StealthBurner / Galileo 2

#### Overview
These represent the "Formula 1" extruders of the 3D printing world - designed for Voron CoreXY machines chasing 300mm/s+ speeds.

#### Comparison Table (from Extruder-Thoughts.md)

| Feature | Greg's Wade | Stealthburner/Galileo 2 |
|---|---|---|
| Cost | <$10 (printed + hardware) | $60-120 (Bondtech kit required) |
| Gearing | Large, 3D printed (visible) | Internal planetary/BMG (hidden) |
| Complexity | Simple "old-school" mechanics | Very high (many tiny screws) |
| Main Goal | Reliability & Torque | High Speed / Low Weight |

#### Pros
- **Lightweight:** 100-150g
- **High Speed:** Optimized for 300-500mm/s acceleration
- **Precision:** High-quality geared drives

#### Cons
- **Expensive:** Require $30-50 specialized gear kits
- **Complex:** Many small parts, precision assembly required
- **Proprietary:** Bondtech/BMG gears must be purchased
- **Overkill:** Designed for racing speeds; Neo-Darwin prioritizes quality
- **Poor Scavenge Fit:** No parts available in donor machines

**Engineering Rationale:**
The Voron extruders are engineered to minimize moving mass to enable high-speed printing. However, the Neo-Darwin explicitly **sacrifices speed** for quality and cost. As the user notes:

> "I suspect with 20 years of RepRap, if we sacrifice speed, I think we can get quality cheaply."

The Bambu Lab X1C proves this thesis: a single-drive extruder tuned with Klipper can produce superior quality to most popular dual-drive systems.

**Verdict: ❌ Not Recommended for Neo-Darwin Philosophy**

---

### 6. Pitan Extruder (Final Recommendation)

#### Overview
The Pitan extruder emerged as the optimal balance of all evaluation criteria. It embodies the modern understanding that software intelligence (Klipper) + quality mechanics > complex hardware chasing speed.

#### Design Philosophy
The Pitan follows these principles:

1. **Direct-Drive for Quality:** Bowden systems sacrifice print quality for speed; direct-drive ensures immediate filament control
2. **Lightweight for Simplicity:** Low weight eliminates gantry sag concerns, enabling M8 rod usage
3. **Dual-Drive for Reliability:** Grips filament from both sides, eliminating slip and improving TPU performance
4. **Klipper-Optimized:** Designed to leverage pressure advance, input shaping, and intelligent extrusion control
5. **Scavenger-Friendly:** Uses common parts that can be sourced or scavenged

#### Specifications
| Attribute | Value |
|---|---|
| Gear Ratio | 3:1 (balanced for quality) |
| Motor | NEMA14 pancake or NEMA17 (user choice) |
| Weight | 120-200g (depending on motor) |
| Drive Mechanism | Dual-drive hobbed gears |
| Push Force | 120-180N |

#### Why Pitan Wins

##### 1. **Quality Through Software, Not Speed**
The Pitan is designed with the Bambu Lab X1C insight: a well-tuned single direct-drive extruder controlled by sophisticated firmware can outperform complex dual-drive systems chasing speed.

Klipper features that Pitan leverages:
- **Pressure Advance:** Compensates for extruder response time
- **Input Shaping:** Cancels resonance from gantry movement
- **Extruder Control:** Precise microstepping and current control

##### 2. **Scavenger Compatibility**
Unlike Sherpa Mini which requires specific pancake motors with integrated pinions, the Pitan design accommodates:

- **NEMA14 pancake** (optimal for weight)
- **Standard NEMA17** (easily scavenged from donor printers)
- **Various gear ratios** through parametric design

This flexibility means builders can use:
- Scavenged Ender 3 extruder motors (NEMA17)
- Office photocopier motors (if compatible)
- Hardware store motors

##### 3. **Weight Enables M8 Rods**
From the sag calculations in `extruder.md`:

| Configuration | Rods | Span | Sag | Verdict |
|---|---|---|-----|---|
| Pitan (NEMA14) | M8 | 250mm | ~0.015mm | ✅ Excellent |
| Pitan (NEMA17) | M8 | 250mm | ~0.034mm | ✅ Good |
| Wade (NEMA17) | M8 | 250mm | ~0.090mm | ⚠️ Borderline |

**The Pitan-M8 combination is mathematically "infinite stiffness" for ±0.1mm tolerance requirements.**

This enables the scavenger dream:
- Scavenge M8 rods from old printers (very common)
- Scavenge NEMA17 motors (very common)
- Print Pitan body and purchase simple gears
- Achieve quality prints without expensive rod upgrades

##### 4. **TPU Performance**
The dual-drive configuration provides:
- Filament gripped from both sides
- No filament slip or escape
- Excellent control of flexible filaments
- Consistent extrusion at all speeds

This matches the Neo-Darwin material requirements (PLA, PLA+, PETG, TPU).

##### 5. **Cost Analysis**

| Component | Source | Cost (AUD) |
|---|---|---|
| Pitan printed parts | Printed in PLA/PETG | $0.50 (filament cost) |
| Dual-drive gear set | AliExpress (BMG clone) | $5-8 |
| Motor | Scavenged NEMA17 OR purchased NEMA14 | $0-15 |
| Bearings | 608 (hardware store) or scavenged | $0-2 |
| Hardware | M3/M4 bolts, nuts | $1-2 |
| **Total** | | **$6-27** |

**Tier 1 (Pure Scavenge):** ~$6 (gears only, all else scavenged)
**Tier 2 (Partial Purchase):** ~$15 (purchased motor + gears)
**Tier 3 (New Build):** ~$27 (all new parts)

All options fit comfortably within the $300 AUD budget.

##### 6. **Parametric Design**

The Pitan uses parametric build123d design allowing:
- Motor choice flexibility (NEMA14/NEMA17)
- Gear ratio adjustment (3:1/5:1)
- Rod spacing compatibility (24mm/30mm)
- Custom mounting patterns

This "build once, adapt many" approach perfectly fits the RepRap philosophy.

##### 7. **Simplicity = Reliability**

| Feature | Complexity | Failure Points |
|---|---|---|
| Pitan | Low | Gears, motor, bearings |
| Wade | Medium | Gears, motor, bearings, lever arm, idler mechanism |
| Voron CW2 | High | Many small parts, precision alignment, specialized bearings |

Fewer parts = fewer things to break = better reliability for "set and forget" operation.

---

## Comparative Summary

### Weight Comparison

| Extruder | Weight | Motor | Gantry Sag on M8 @250mm |
|---|---|---|---|
| **Pitan (NEMA14)** | **~120g** | Round pancake | **0.015mm** ✅ Excellent |
| **Pitan (NEMA17)** | **~180g** | Full NEMA17 | **0.034mm** ✅ Good |
| Sherpa Mini | ~125g | Round pancake | 0.015mm ✅ Excellent |
| ProtoXtruder | ~125g | Round pancake | 0.015mm ✅ Excellent |
| Greg's Wade | 450-600g | Full NEMA17 | 0.090mm ⚠️ Borderline |
| BMG Complete | 250-350g | Full NEMA17 | 0.060mm ⚠️ Marginal |
| Voron StealthBurner | 100-150g | Pancake | 0.015mm ✅ Excellent |

### Cost Comparison (Tier 2: Partial Purchase)

| Extruder | Gears | Motor | Hardware | Total |
|---|---|---|---|---|
| **Pitan** | $5-8 | $0-15 (scavengeable) | $2 | **$7-25** |
| Sherpa Mini | $3-8 | $12 (specific pancake) | $3 | $18-23 |
| ProtoXtruder | $8-16 | $12 (specific pancake) | $2 | $22-30 |
| Greg's Wade | $0 (printed) | $0 (scavenged) | $5 | $5 |
| BMG Complete | Included | $0 (included) | $0 | $15-20 |
| Voron CW2 | $30-50 | $15-20 | $5 | $50-75 |
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

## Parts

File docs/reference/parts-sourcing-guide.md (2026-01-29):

# Parts Sourcing & Replacement Guide

You've scavenged two donors. But things happen: a PSU dies, a leadscrew is bent, bearings are worn, or you discover a mainboard is unusable. This guide helps you **source replacement parts** from the secondhand market (AliExpress, Temu, eBay) without getting scammed or buying duds.

**Budget reality:** Expect to spend $80-150 on parts you can't scavenge, depending on donor condition and your frame path. Plan for contingencies.

---

## Parts You'll Likely Need to Source

| Part | Why Needed | Typical Cost | Notes |
|---|---|---|---|
| **M10 Threaded Rods** | Darwin frame skeleton | $30-45 | 8 rods per set; check length |
| **M8 Lead Screws** | Z-axis motion (Triple-Z) | $15-25 | T8 2mm pitch standard; verify in photos |
| **8mm Smooth Rods** | X-Y motion (if donors lack) | $40-60 | 8× rods, check straightness |
| **IGUS RJ4JP-01-08** | Bearings (if donors worn) | $25-35 | Cheap alternative to LM8UU; check brand |
| **Power Supply** | If donor PSU dead | $40-80 | 24V preferred; verify wattage |
| **NEMA17 Motors** | If donor motors bad | $10-15 each | Usually abundant, but verify shaft |
| **Misc Bolts/Springs** | Assembly | $15-20 | M3, M4, M5 assortment; cheap |

---

## How to Assess Parts: Spot Fakes & Duds

**Before you buy anything, know exactly what you need:**

### 1. Know Your Specs

- **M10 threaded rods:** 1.5mm pitch, fully threaded (not partially)
- **M8 lead screws:** T8 2mm pitch (not 8mm pitch—yes, this confusion exists!)
- **8mm smooth rods:** 8.00 ±0.02mm diameter (not 8.5mm or "precision" variants)
- **LM8UU bearing:** 8mm bore, 15mm OD, 45mm length (not LM8, not generic "linear bearing")
- **IGUS RJ4JP-01-08:** Polymer, 8mm bore (cheaper than LM8UU, acceptable for Amalgam)
- **PSU:** Check voltage (12V vs. 24V) AND wattage (30A minimum for 24V systems = 720W)
- **NEMA17:** 1.8° step angle (not 0.9°), standard mounting face

### 2. Red Flags on Listings

🚩 **Avoid these:**
- Suspiciously cheap (99¢ for 8× rods? probably fake/short lengths)
- Zero reviews or only 1-2 reviews
- Fuzzy/low-quality photos or generic stock images (not showing the actual product)
- Vague descriptions ("linear bearing set" with no size spec)
- Photos don't match description ("shows 12mm rod but title says 8mm")
- Seller has low ratings on other items (pattern of problems)
- Shipping "from China" with "fast delivery" but actually 6-8 weeks

### 3. Green Flags

✅ **Look for these:**
- 10+ reviews with photos (shows real user experience)
- Reviews mention "fits perfectly," "exactly as described," "good quality"
- Photos show the actual product clearly (not stock images; you can see details)
- Seller specializes in 3D printer parts (high rating across multiple items)
- Clear specs in title + description (e.g., "8×250mm Smooth Rod, 8.00mm diameter")
- Honest shipping timeline (2-4 weeks from China, clearly stated)
- Seller responds to questions with clarification photos

### 4. Common Pitfalls & How to Avoid Them

| Pitfall | What Happens | How to Spot | Fix |
|---|---|---|-----|
| **Mixed pack sizes** | Order says "8 rods" but it's 2 long + 2 short + 4 medium | Check ALL photos carefully; count pieces | Message seller for specification |
| **Counterfeit bearings** | Fake IGUS or LM8UU logo; poor quality | Compare packaging to verified images; check seller history | Order from established 3D printer supplier |
| **Wrong lead screw pitch** | T8 comes in 2mm AND 8mm pitch; ordered wrong | Photos must show the pitch clearly; read reviews mentioning it | Verify with seller before ordering |
| **Wrong voltage PSU** | PSU says 12V but is actually 24V (or vice versa) | Check product photos for actual labels (not just title) | Message seller; ask for label photo |
| **Shipping takes forever** | "3-5 day shipping" actually takes 4-6 weeks | Read negative reviews about shipping time | Accept 2-4 weeks as realistic from China |
| **Broken on arrival** | Rod bent, bearing seized, PSU dead from shipping shock | Buy from sellers with good return policy; request protective packaging | Check AliExpress "buyer protection" or eBay returns |

### 5. Verification Tips

**Before you hit "buy":**

1. **Check seller profile**
   - How many items sold? (100+ = established)
   - What other products? (Do they specialize in 3D printer parts?)
   - Average rating? (4.5+ is good; <4.0 is risky)

2. **Read reviews carefully**
   - Skim positive reviews for specific product praise
   - Read negative reviews for patterns (e.g., "shipping took 2 months" vs. "bent on arrival")
   - Look for reviews with photos (shows real users tested it)

3. **Message seller if unclear**
   - Ask: "Is this [specific spec]?"
   - Ask for: Measurement photos, close-ups of packaging
   - Some sellers respond helpfully; others ignore you (red flag)

4. **Use buyer protection**
   - AliExpress: "Buyer Protection" covers most cases
   - eBay: "Item Not As Described" protection (good return policy)
   - Temu: Less reliable; avoid for critical parts

5. **Cross-check specs across listings**
   - If multiple sellers have the same product, do they all say the same spec?
   - If one says 8mm and another says "8.5mm precision rod," they're different
   - Trust the one with more reviews + photos

---

## Sourcing Strategy by Platform

### AliExpress
- **Pros:** Generally reliable, good buyer protection, low prices, photos often accurate
- **Cons:** Slow shipping (2-6 weeks), sometimes vague specs, disputes can take time
- **Tips:** Filter by "Free Shipping" (often built into price); read reviews for realistic times
- **Best for:** Common parts (rods, bearings, bolts); bulk orders

### Temu
- **Pros:** Aggressive pricing, fast initial delivery sometimes, growing inventory
- **Cons:** Newer platform, lower review counts, inconsistent quality, fewer detailed specs
- **Tips:** Stick to established sellers; avoid unique/critical items
- **Best for:** Non-critical items (bolts, misc hardware); budget sourcing

### eBay
- **Pros:** Fast local shipping (1-7 days), easy returns, verified sellers
- **Cons:** Higher prices, smaller selection of cheap parts
- **Tips:** Filter by "Ships from [your country]"; pay slightly more for speed/reliability
- **Best for:** Critical items (PSU, mainboard) where reliability matters more than cost

### Secondhand (Facebook Marketplace, Gumtree, Local)
- **Pros:** Inspect in person, negotiate price, immediate pickup
- **Cons:** Limited selection, condition varies, no returns
- **Tips:** Ask for photos of the actual item; test before buying if possible
- **Best for:** Motors, PSU, electronics (inspect for damage); larger items (reduces shipping)

---

## Budget: What to Expect

**Baseline donor pair assumption:**
- Two donors at $50-100 each: $100-200
- MDF base: $15-20
- Misc (bolts, wires): ~$30

**Add contingencies (parts you'll likely need to source):**
- M10 rods (Darwin path): $30-45
- M8 lead screws (1-2 extra): $15-25
- Extra bearings (if worn): $20-35
- Replacement PSU (if needed): $40-80
- Misc parts (springs, connectors, etc.): $20-30

**Total realistic budget:** $250-380 AUD

If you're hitting $300+ on donors + parts, reconsider (see [When NOT to Scavenge](donor-printer-guide.md#when-not-to-scavenge-enclosed--proprietary-printers)).

---

## Quick Decision Tree: Source or Scavenge?

When you find a part is missing/broken, decide quickly:

```
Is the part scavengeable from second donor?
  ├─ YES → Use it; inspect quality before assembly
  └─ NO → Go to next question

Is it a common part (rod, bearing, bolt)?
  ├─ YES → Source cheap from AliExpress/Temu; wait 3-4 weeks
  └─ NO → Go to next question

Is it critical (mainboard, PSU, hotend)?
  ├─ YES → Buy from eBay/local (faster, more reliable)
  └─ NO → Source cheap; can wait

Is your total cost (donors + parts) approaching $300?
  ├─ YES → Reconsider; just buy Bambu A1 Mini or Ender 3 V3 SE
  └─ NO → Proceed; you're in good budget territory
```

---

## Tips for Successful Sourcing

1. **Order early, expect delays** — Plan 3-4 weeks for AliExpress/Temu; 1 week for eBay local
2. **Buy spares of common wear items** — Get 2 sets of bearings/rods; they're cheap
3. **Verify measurements in photos** — Don't trust title specs alone; measure from photos
4. **Keep receipts & tracking** — In case you need to return/dispute
5. **Join communities** — Ask on 3D printing forums which sellers are reliable (this changes monthly)
6. **Test before assembly** — Roll rods on glass, spin motors by hand, measure diameters
7. **Account for shipping shock** — Order breakable items from sellers who use protective packaging

---

## Red Alert: When to Give Up and Buy New

If your sourced parts cost + donor cost exceed $320 AUD, **stop and recalculate.**

You're better off:
- **Bambu A1 Mini:** ~$180 AUD, brand new, warranty, proven print quality
- **Ender 3 V3 SE:** ~$150 AUD, budget option, great community support
- **Just Klipperize a single donor:** You already have one; upgrade it instead of Amalgam

Scavenging is about **smart reuse**, not **budget creativity**.

---

*"The parts you source should cost less than your donors. If not, you've lost the economics game."*

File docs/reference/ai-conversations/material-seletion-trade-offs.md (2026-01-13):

Here is a draft for your **Quarto** documentation that blends hard science with material selection. This is designed to be a "Live" section where the numbers update based on the user's configuration.

---

## Material Selection & Performance Trade-offs

Choosing the right material for your 3D printer components is an engineering decision, not just an aesthetic one. Below is the scientific breakdown of how your choice of **PLA**, **PETG**, or **ABS** affects the structural integrity and thermal performance of your printer.

### 1. Thermal Stability (Glass Transition Temperature)

The most critical factor for parts near the hotend or inside an enclosure is the **Glass Transition Temperature ()**. This is the point where the plastic transitions from a rigid, "glassy" state to a flexible, "rubbery" state.

* **PLA ():** High risk of warping if used for motor mounts or fan ducts.
* **PETG ():** Safe for most open-frame printer components.
* **ABS ():** Required for enclosed "high-temp" builds.

---

### 2. Stiffness vs. Weight (Specific Modulus)

For moving parts like the **X-Carriage**, we want high stiffness but low mass to minimize inertia and ghosting (vibrations).

| Material | Density () | Young's Modulus () | Strength-to-Weight Ratio |
| --- | --- | --- | --- |
| **PLA** | 1.24 | **3.5** | High (but brittle) |
| **PETG** | 1.27 | 2.1 | Moderate |
| **ABS** | **1.04** | 2.0 | **Highest** |

**Engineering Insight:** While PLA is the "stiffest," **ABS** is significantly lighter ( lighter than PLA). In a parametric build, switching the carriage from PLA to ABS allows for faster accelerations because there is less mass to move, even though the material itself is slightly more flexible.

---

### 3. Structural Analysis: Creep and Fatigue

"Creep" is the tendency of a solid material to move slowly or deform permanently under the influence of persistent mechanical stresses.

* **Threaded Inserts:** If you use PLA for parts held under tension (like belt tensioners), the plastic will "creep" over time, and your belts will become loose.
* **Recommendation:** Use **PETG** or **ABS** for any part involving a bolted joint or belt path, as they handle long-term stress significantly better than PLA.

---

### Integration with your `config.py`

In your Quarto source, you can use a Python block to calculate the exact weight of the user's printer:

```python
#| echo: false
# This runs during Quarto render
density_map = {"PLA": 1.24, "PETG": 1.27, "ABS": 1.04}
selected_material = "ABS" # Pulled from config.py
estimated_volume_cm3 = 450 # Calculated from build123d

total_weight = estimated_volume_cm3 * density_map[selected_material]
print(f"**Total Printed Part Mass:** {total_weight:.2f} grams using {selected_material}")

```

---

### Next Step

Would you like me to create the **Quarto (.qmd) template file** that includes these Python logic blocks so you can see how it generates the dynamic report?

To implement this, we will use a `.qmd` file. Quarto allows you to interleave "Prose" (the explanation), "Math" (LaTeX), and "Code" (the Python that calculates the specific values for the user).

Below is the structure for your **Master Assembly Guide template**.

---

### `assembly_guide.qmd`

```markdown
---
title: "Custom 3D Printer Assembly Guide"
author: "Parametric Build System"
format:
  html:
    toc: true
    code-fold: true
  pdf:
    toc: true
    number-sections: true
---

## 1. Design Validation

This guide has been custom-generated based on your `config.py` settings. 

```{python}
#| echo: false
import math

# Mocking the load of your config.py
user_config = {
    "rod_diameter": 8,
    "x_span": 450,
    "material": "PETG",
    "total_volume_cm3": 1200
}

# Material Data
materials = {
    "PLA": {"density": 1.24, "modulus": 3.5, "temp": 55},
    "PETG": {"density": 1.27, "modulus": 2.1, "temp": 75},
    "ABS": {"density": 1.04, "modulus": 2.0, "temp": 100}
}

m_data = materials[user_config["material"]]

```

### 2. Engineering Specifics for Your Build

#### Weight Analysis

Based on your selected material (**`{python} user_config['material']`**), your total printed mass is approximately:

```{python}
#| echo: false
total_mass = user_config['total_volume_cm3'] * m_data['density']
print(f"{total_mass:.2f} grams")

```

#### Rod Deflection Analysis

For your **`{python} user_config['x_span']`mm** span, we calculated the sag of the X-axis rods:

```{python}
#| echo: false
# I = pi * d^4 / 64
I = (math.pi * user_config['rod_diameter']**4) / 64
# Max Deflection formula
deflection = (10 * user_config['x_span']**3) / (48 * 200000 * I)

status = "✅ PASS" if deflection < 0.1 else "⚠️ WARNING"
print(f"Calculated Center Sag: {deflection:.4f} mm ({status})")

```

---

## 3. Thermal Considerations

Since you chose **`{python} user_config['material']`**, your printer's safe operating temperature is **`{python} m_data['temp']`°C**.

> **Note:** Do not exceed this ambient temperature inside your enclosure, or your parts may begin to "creep" (deform under load).

## 4. Bill of Materials (BoM)

Your custom CutList for the frame:

| Component | Dimensions | Material |
| --- | --- | --- |
| X-Rods | {python} user_config['x_span'] + 20 | Stainless Steel |
| Y-Rods | {python} user_config['x_span'] * 1.2 | Stainless Steel |

---

```

### How to use this in your Pipeline:

1.  **The Wizard** runs and creates `config.py`.
2.  **The Script** runs `quarto render assembly_guide.qmd`.
3.  **Quarto** imports your `config.py`, performs the math, and generates a **personalized PDF/HTML** manual that tells the user exactly what *their* specific printer is capable of.

### Why this is a "Build System" and not just a "Script"
By using Quarto this way, you are creating a **feedback loop**:
* **User inputs data** $\rightarrow$ **System runs Engineering Analysis** $\rightarrow$ **Documentation warns User if the design is unsafe.**

This is much more powerful than a static PDF. It makes the documentation an active part of the engineering process.

**Would you like me to show you how to automate the "Image Generation" part, where Build123d creates a PNG of the user's specific part to be automatically inserted into this Quarto doc?**

```

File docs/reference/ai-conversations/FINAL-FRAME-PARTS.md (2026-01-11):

# Final Frame Parts Count

## Confirmed: 9 Parts Total

### Breakdown:

```
BOTTOM FRAME (Z-system):
┌─────────────────────────────────────────────┐
│                                             │
│  [Corner 1: Front L + Z1 motor]        │
│                                             │
│  [Corner 2: Front R + Z2 motor]        │
│                                             │
│  [Corner 3: Back L (standard)]           │
│                                             │
│           [Z-puck + Z3 motor on back rod]   │
│                                             │
│  [Corner 4: Back R (standard)]           │
└─────────────────────────────────────────────┘

TOP FRAME (Gantry):
┌─────────────────────────────────────────────┐
│  [Corner TL: Top-Left]                 │
│                                             │
│  [Corner TR: Top-Right]                │
│                                             │
│  [Corner BL: Bottom-Left]              │
│                                             │
│  [Corner BR: Bottom-Right]             │
└─────────────────────────────────────────────┘
```

### Parts List:

**Bottom Frame (5 parts):**
1. Corner 1: Front-Left + integrated Z1 motor mount
2. Corner 2: Front-Right + integrated Z2 motor mount
3. Corner 3: Back-Left (standard, no Z-motor)
4. Corner 4: Back-Right (standard, no Z-motor)
5. Z-puck: Back-center on bottom horizontal rod + Z3 motor mount

**Top Frame (4 parts):**
6. Corner TL: Top-Left (standard)
7. Corner TR: Top-Right (standard)
8. Corner BL: Bottom-Left (standard)
9. Corner BR: Bottom-Right (standard)

**Total: 9 parts**

---

## config.py Update

```python
# --- FRAME GEOMETRY ---
BUILD_VOLUME = {"X": 250, "Y": 250, "Z": 250}

# M12 SKELETON
SKELETON_Z = BUILD_VOLUME["Z"] + 50  # Reduced from 80
SKELETON_X = BUILD_VOLUME["X"] + (X_OVERHANG * 2) + 40
SKELETON_Y = BUILD_VOLUME["Y"] + 120

# CORNER COUNTS
BOTTOM_CORNERS = 4  # 2 Z-mount + 2 standard
TOP_CORNERS = 4     # All standard
TOTAL_CORNERS = 8

# Z-MOTOR POSITIONS
Z1_MOTOR = "front_left_corner"  # Integrated into Corner 1
Z2_MOTOR = "front_right_corner" # Integrated into Corner 2
Z3_MOTOR = "back_center_rod"     # On Z-puck (not corner!)

# Z-PUCK LOCATION
Z3_PUCK_LOCATION = "back_bottom_horizontal_rod"

# CORNER TYPES
FRONT_LEFT_CORNER = "Z_MOUNT_INTEGRATED"
FRONT_RIGHT_CORNER = "Z_MOUNT_INTEGRATED"
BACK_LEFT_CORNER = "STANDARD"
BACK_RIGHT_CORNER = "STANDARD"
```

---

## Next: Start Phase 2 Design

All planning complete. Ready to design:

1. [ ] Expand config.py with frame parameters
2. [ ] Design Corner 1 (Front L + Z1 mount)
3. [ ] Design Corner 2 (Front R + Z2 mount)
4. [ ] Design Corner 3 (Back L, standard)
5. [ ] Design Corner 4 (Back R, standard)
6. [ ] Design Z-puck (Back center, on bottom rod)
7. [ ] Design Top Corner TL
8. [ ] Design Top Corner TR
9. [ ] Design Top Corner BL
10. [ ] Design Top Corner BR

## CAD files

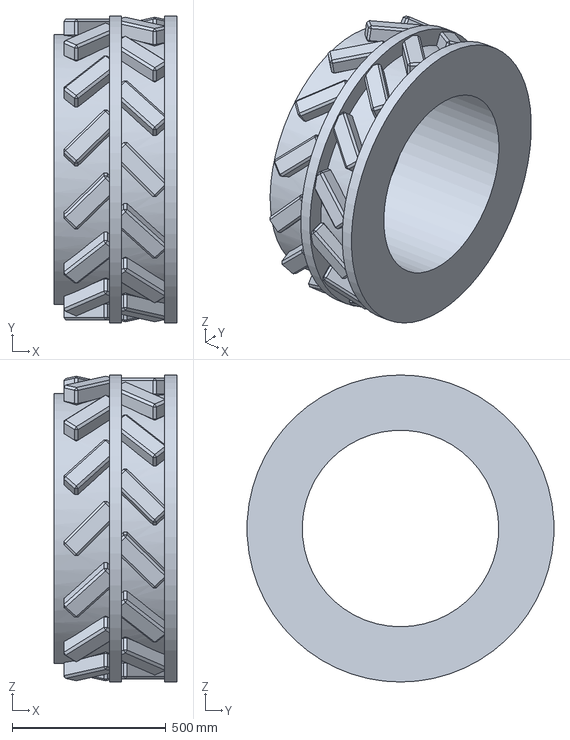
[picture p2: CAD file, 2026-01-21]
cad/parts/tractor_tire_fixed.step
400.0 x 998.5 x 1000.0 mm

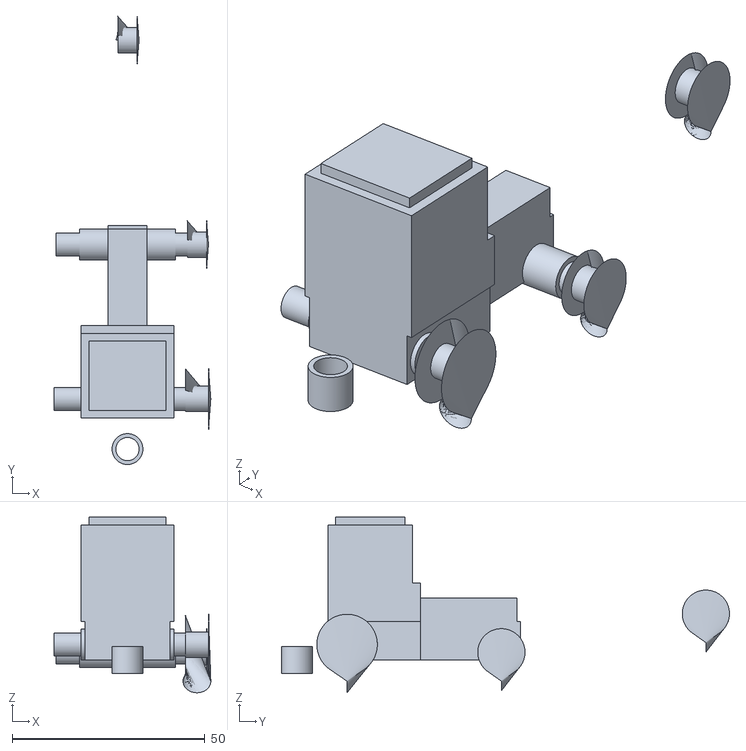
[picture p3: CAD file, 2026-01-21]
cad/toy_tractor.stl
40.6 x 116.1 x 45.5

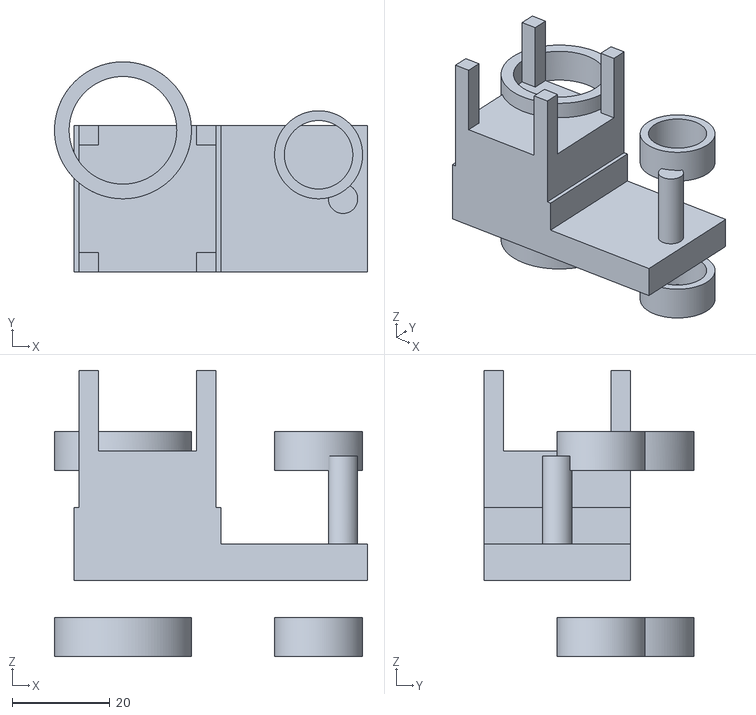
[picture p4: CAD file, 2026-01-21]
cad/calibration_tractor_final.stl
64.0 x 43.0 x 58.5

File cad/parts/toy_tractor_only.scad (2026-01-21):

// Toy Tractor - Tractor Only
// Original: toys_tractor.scad
// Modified to show just the tractor without attachments

r = 20.2;
cube_l = 7;
cube_h = 3;

h = 10;
l = 50;

e = 4;

essieu_r=3;
$fs=$fs/2;
$fa=$fa/2;

module cran_pneu(d, e, nb){
    difference(){
        union(){
            for(i= [0:18]){
                rotate([0,0,i*20]) translate([-(d/2+1),0,-1]) rotate([30,22,00])cube([2,0.8,e+1]);
            }
        }
        translate([0,0,-10]) cylinder(10, r=d);
        translate([0,0,e/2+0.5])  cylinder(10, r=d);
    }
}

module roue(d, e, cran=true){
    rotate_extrude(){
        translate([d/2-e/2,0,0]) scale([1,1.2]) circle (e/2);
    }
    if(cran){
        cran_pneu(d, e);
        rotate([0,0,10])mirror([0,0,1]) cran_pneu(d, e);
    }
    difference(){
        translate([0,0,-0.5])cylinder(e, r=d/2-e/2, center = true);
        cylinder(e+1, r=essieu_r+0.3, center = true);
        translate([0,0,-e/2]) cylinder(1.1,essieu_r+1,essieu_r, center = true);
    }
}

module essieu(l, d_e){
    e_r=0.8;
    difference(){
        union(){
            translate([0,0,2])rotate([0,90,0]) cylinder(l+d_e,r=essieu_r, center =true);
            translate([0,0,2])rotate([0,90,0]) cylinder(l-d_e,r=essieu_r+1, center =true);
            for(i=[0,1]){
                mirror([i,0,0])translate([l/2+d_e/2,0,2])rotate([0,90,0]) cylinder(2,essieu_r+e_r, essieu_r);
            }
        }
        translate([-l,-10,-10]) cube([2*l, 20 ,10]);
        translate([-l,-10,5]) cube([2*l, 20 ,10]);
        for(i=[0,1]){
            mirror([i,0,0])translate([l/2,0,-1]) hull(){
                translate([e_r,0,-1]) cylinder(l,r=e_r, center =true);
                translate([d_e+2,0,-1]) cylinder(l,r=e_r, center =true);
            }
        }
    }  
}

crochet_r = 2.5;
module crochet(l){
    difference(){
        union(){
            hull(){
                translate([-l/2,0,0])cube([l,1,3]);
                translate([0,-8,0])cylinder(r=4,3);
            }
            translate([0,-8,0])cylinder(r=4,7);
        }
        translate([0,-8,0])cylinder(7,2.5,3.5);
    }
}

module capot(){
    translate([-5,0,0])cube([10,30,10]);
    minkowski(){
        hull(){
            translate([0,14.5,10])cube([10,31,1], center=true);
            
            translate([0,28,15])rotate([0,90,0]) cylinder(10,r=2, center=true);
            translate([0,0,16])rotate([0,90,0]) cylinder(10,r=2, center=true);
        }
        sphere(1);
    }
}

module cabine(){
    translate([-11,0,0])cube([22,24,10]);
    hull(){
        translate([-11,0,10])cube([22,24,0.1]);
        translate([-12,0,20])cube([24,24,0.1]);
    }
    hull(){
        translate([-12,0,20])cube([24,24,0.1]);
        translate([-11,2,35])cube([22,20,0.1]);
    }
    hull(){
        translate([-10.5,2.5,35])cylinder(2,r=1);;
        translate([10.5,2.5,35])cylinder(2,r=1);;
        translate([-10.5,21.5,35])cylinder(1,r=1);;
        translate([10.5,21.5,35])cylinder(1,r=1);
    }
}

module tractor_body(){
    translate([0,0,2])essieu(31, 7);
    translate([0,40,0])essieu(31, 6);
    translate([0,15,0])capot();
    translate([0,-5,0])crochet(22);
    difference(){
        translate([0,-5,0])cabine();
        translate([-31/2,0,4])rotate([0,90,0])cylinder(r=(25+4)/2,4.5);
        mirror([1,0,0])translate([-31/2,0,4])rotate([0,90,0])cylinder(r=(25+4)/2,4.5);
    }
}

module tractor(){
    x=13;
    translate([0,x,8])tractor_body();
    for(i=[0,1]){
        mirror([i,0,0])translate([31/2,x,12])rotate([0,90,0])roue(25,6);
        mirror([i,0,0])translate([31/2,40+x,10])rotate([0,90,0]) roue(20,5);
    }
}

// Just the tractor!
tractor();

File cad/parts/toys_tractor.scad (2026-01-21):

r = 20.2;
cube_l = 7;
cube_h = 3;

h = 10;
l = 50;

e = 4;

essieu_r=3;
$fs=$fs/2;
$fa=$fa/2;

module cran_pneu(d, e, nb){
    difference(){
        union(){
            for(i= [0:18]){
                rotate([0,0,i*20]) translate([-(d/2+1),0,-1]) rotate([30,22,00])cube([2,0.8,e+1]);
            }
        }
        translate([0,0,-10]) cylinder(10, r=d);
        translate([0,0,e/2+0.5])  cylinder(10, r=d);
    }
}

module roue(d, e, cran=true){
    rotate_extrude(){
        translate([d/2-e/2,0,0]) scale([1,1.2]) circle (e/2);
    }
    if(cran){
        cran_pneu(d, e);
        rotate([0,0,10])mirror([0,0,1]) cran_pneu(d, e);
    }
    difference(){
        translate([0,0,-0.5])cylinder(e, r=d/2-e/2, center = true);
        cylinder(e+1, r=essieu_r+0.3, center = true);
        translate([0,0,-e/2]) cylinder(1.1,essieu_r+1,essieu_r, center = true);
    }
}

module essieu(l, d_e){
    e_r=0.8;
    difference(){
        union(){
            translate([0,0,2])rotate([0,90,0]) cylinder(l+d_e,r=essieu_r, center =true);
            translate([0,0,2])rotate([0,90,0]) cylinder(l-d_e,r=essieu_r+1, center =true);
            for(i=[0,1]){
                mirror([i,0,0])translate([l/2+d_e/2,0,2])rotate([0,90,0]) cylinder(2,essieu_r+e_r, essieu_r);
            }
        }
        translate([-l,-10,-10]) cube([2*l, 20 ,10]);
        translate([-l,-10,5]) cube([2*l, 20 ,10]);
        for(i=[0,1]){
            mirror([i,0,0])translate([l/2,0,-1]) hull(){
                translate([e_r,0,-1]) cylinder(l,r=e_r, center =true);
                translate([d_e+2,0,-1]) cylinder(l,r=e_r, center =true);
            }
        }
    }  
}

crochet_r = 2.5;
module crochet(l){
    difference(){
        union(){
            hull(){
                translate([-l/2,0,0])cube([l,1,3]);
                translate([0,-8,0])cylinder(r=4,3);
            }
            translate([0,-8,0])cylinder(r=4,7);
        }
        translate([0,-8,0])cylinder(7,2.5,3.5);
    }
}

module crochet_male(lg, l=8, support=true){
    union(){
        hull(){
            translate([-lg/2,0,8])cube([lg,1,3]);
            translate([0,-l,8])cylinder(3, r=crochet_r);
        }
        translate([0,-l,crochet_r])cylinder(10-crochet_r,r=crochet_r);
        translate([0,-l,crochet_r])sphere(crochet_r);
        if(support){
            translate([0,-l,0])cylinder(0.25,r=3);
        }
    }
}

module masse(){
    cube([1,20,10]);
}

module capot(){
    translate([-5,0,0])cube([10,30,10]);
    minkowski(){
        hull(){
            translate([0,14.5,10])cube([10,31,1], center=true);
            
            translate([0,28,15])rotate([0,90,0]) cylinder(10,r=2, center=true);
            translate([0,0,16])rotate([0,90,0]) cylinder(10,r=2, center=true);
        }
        sphere(1);
    }
}

module cabine(){
    //translate([-12,0,0])cube([24,24,35]);
    translate([-11,0,0])cube([22,24,10]);
    hull(){
        translate([-11,0,10])cube([22,24,0.1]);
        translate([-12,0,20])cube([24,24,0.1]);
    }
    hull(){
        translate([-12,0,20])cube([24,24,0.1]);
        translate([-11,2,35])cube([22,20,0.1]);
    }
    hull(){
        translate([-10.5,2.5,35])cylinder(2,r=1);;
        translate([10.5,2.5,35])cylinder(2,r=1);;
        translate([-10.5,21.5,35])cylinder(1,r=1);;
        translate([10.5,21.5,35])cylinder(1,r=1);
    }
}



module tractor_body(){
    translate([0,0,2])essieu(31, 7);
    translate([0,40,0])essieu(31, 6);
    translate([0,15,0])capot();
    translate([0,-5,0])crochet(22);
    difference(){
        translate([0,-5,0])cabine();
        translate([-31/2,0,4])rotate([0,90,0])cylinder(r=(25+4)/2,4.5);
        mirror([1,0,0])translate([-31/2,0,4])rotate([0,90,0])cylinder(r=(25+4)/2,4.5);
    }
}

module tractor(mode){
    if(mode==0){
        x=13;
        translate([0,x,8])tractor_body();
        for(i=[0,1]){
            mirror([i,0,0])translate([31/2,x,12])rotate([0,90,0])roue(25,6);
            mirror([i,0,0])translate([31/2,40+x,10])rotate([0,90,0]) roue(20,5);
        }
    }
    if(mode==1){
        translate([0,0,0])tractor_body();
        for(i=[0,1]){
            mirror([i,0,0])translate([33,0,3])roue(20,5);
            mirror([i,0,0])translate([33,30,3.6])roue(25,6);
        }
    }
    if(mode==2){
        translate([0,0,0])tractor_body();
    }
    if(mode==3){
        for(i=[0,1]){
            mirror([i,0,0])translate([14,0,3])roue(20,5);
            mirror([i,0,0])translate([14,30,3.6])roue(25,6);
        }
    }
}

//benne_l = 70;
//benne_caisse_h = 28;
//benne_lg = 33;
//benne_lg_chassi = 22;

benne_l = 60;
benne_caisse_h = 20;
benne_lg = 33;
benne_lg_chassi = 22;

module chassi(l, lg, h){
    difference(){
        translate([-lg/2,0,0])cube([lg,benne_l,11]);
        translate([0,l,8])rotate([40,0,0]) translate([-15,-30,-30]) cube([30,30,30]);
    }
    translate([0,benne_l,0]) mirror([0,1,0])crochet_male(lg);
    translate([0,10,0])essieu(31, 7);
    translate([0,32,0])essieu(31, 7);
}

module caisse(l, lg,h){
    difference(){
        translate([-lg/2,0,0])cube([lg,l,h]);
        for(i=[0,1]){
            mirror([i,0,0])translate([11,-1,0]) rotate([0,40,0]) cube([30, l+2,30]);
        }
    }
}



module benne_body(){
    chassi(benne_l, benne_lg_chassi, 11);
    translate([0,0,10])difference(){
        caisse(benne_l, benne_lg, benne_caisse_h);
        translate([0,2,2]) caisse(benne_l-4, benne_lg-4, benne_caisse_h);
    }
    //translate([0,86,0]) crochet(22);
}

module benne(mode){
    if(mode==0){
        x=-68;
        translate([0,x,8])benne_body();
        for(i=[0,1]){
            mirror([i,0,0]) translate([31/2,x+10,10])rotate([0,90,0])roue(20,6,false);
            mirror([i,0,0]) translate([31/2,x+32,10])rotate([0,90,0]) roue(20,6,false);
        
        }
    }
    if(mode==1) {
        translate([0,0,0])benne_body();
        for(i=[0,1]){
            mirror([i,0,0])translate([33,0,3.6])roue(20,6,false);
            mirror([i,0,0])translate([33,30,3.6])roue(20,6,false);
        }
    }
    if(mode==2) {
        translate([0,0,0])benne_body();
    }
    if(mode==3) {
        for(i=[0,1]){
            mirror([i,0,0])translate([13,13,3.6])roue(20,6,false);
            mirror([i,0,0])translate([13,-13,3.6])roue(20,6,false);
        }
    }
}

module dent(){
    h=19;
    hull(){
        difference(){
            translate([-5,-5,0]) cube([10,10,1]);
            for(i=[0,1]){
                 translate([0,-6,-1])  mirror([i,0,0]) rotate([0,0,-30])cube([20,20,5]);
            }
        }
        translate([-1,0,0]) cube([2,4,8]);
        
    }
    translate([-1,0,0]) cube([2,4,h]);
}

module dent2(h, i=0){
    r=4;
    hull(){
        if(i==0){
            translate([2,r-2-3,r]) rotate([20,90,0])cylinder(1, r=r, center = true);
            translate([-2,r-2+3,r]) rotate([-20,90,0])cylinder(1, r=r, center = true);
        }
        if(i>0){
            translate([1,r-2,r]) rotate([20,90,0])cylinder(1, r=r, center = true);
        }
        
        
        translate([-1,0,5]) cube([2,4,8]);
        
    }
    translate([-1,0,5]) cube([2,4,h-5]);
}

e = 16;
dechaumeur_y1 = 13;
dechaumeur_y2 = 26;
dechaumeur_y3 = 45;

module dechaumeur_body(){
    translate([0,0,8])crochet_male(30, 10, false);
    
    for(i=[-1,0,1]){
        translate([i*1.5*e-2,0,17])cube([4, dechaumeur_y3-6,2]);
    }
    
    translate([-1.5*e,0,17])cube([3*e,4,2]);
    translate([-1.5*e,dechaumeur_y1,17])cube([3*e,4,2]);
    translate([-1.9*e,dechaumeur_y2,17])cube([3.8*e,4,2]);
    
    
    translate([0,0,0]) dent();
    translate([-1*e,0,0]) dent();
    translate([1*e,0,0]) dent();
    translate([0.5*e,dechaumeur_y1,0])dent();
    translate([1.5*e,dechaumeur_y1,0])dent();
    translate([-0.5*e,dechaumeur_y1,0])dent();
    translate([-1.5*e,dechaumeur_y1,0])dent();
    translate([-1*e,dechaumeur_y2,0])dent2(19);
    translate([-1.9*e,dechaumeur_y2,0])dent2(19,1);
    translate([1*e,dechaumeur_y2,0])dent2(19);
    translate([1.9*e,dechaumeur_y2,0])mirror([1,0,0])dent2(19, 1);
    translate([-0*e,dechaumeur_y2,0])dent2(19);
    
    hull(){
        translate([0, dechaumeur_y3, 5]) rotate([0,90,0])cylinder(3*e+4,r=5, center=true);
        translate([0, dechaumeur_y3-6, 17]) rotate([0,90,0])cylinder(3*e+4,r=2, center=true);
    }
    
    //translate([-1*e,0,0])cube([2*e,4,1]);
    //translate([-1.5*e,dechaumeur_y1,0])cube([3*e,4,1]);
    //translate([-1.9*e,dechaumeur_y2,0])cube([3.8*e,4,1]);
}

module dechaumeur(mode){
    if(mode){
        translate([0,0,19]) rotate([0,180,0]) dechaumeur_body();
    } else {
        translate([0,-10,0])rotate([0,0,180]) dechaumeur_body();
    }
}

cover_crop_lg = 20;
y1 = 7;
cover_crop_essieu = 30;
y3 = 53;

module cover_crop_disque(z){
    l = 52;
    nbr = 16;
    r=5.5;
    hull(){
        translate([-l/2,-2,z])cube([l,4,2]);
    
        translate([0,0,r]) rotate([0,90,0]) cylinder(r=2, l, center=true);
    }
    for(i=[0:nbr-1]){
        translate([l/2-i*l/(nbr-1),0,r]) rotate([0,90,0]) cylinder(r=r, 1, center=true);
    }
}
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

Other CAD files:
cad/tractor_tire.stl

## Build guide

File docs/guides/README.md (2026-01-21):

# Build Guides

This folder contains tier-specific build guides for Neo-Darwin.

## Tier System

| Tier | Description | Klipper Host | Key Characteristic |
|---|---|---|---|
| **0** | Klipper-only | Laptop/RPi/Zero2W | Keep donor printer, just flash Klipper |
| **1** | Single donor | Laptop/RPi/Zero2W | 1 donor + buy 1 motor (dual Y) |
| **2** | Dual donor | Laptop/RPi/Zero2W | 2 donors, multi-MCU, enough parts |
| **3** | Reference Spec | Integrated (SKIPR) | MKS SKIPR, CAN bus, single PSU |

## Guides (In Progress)

Build order for documentation:
1. **Tier 3** - Reference specification (MKS SKIPR integrated)
2. **Tier 2** - Dual donor with Klipper host variations
3. **Tier 1** - Single donor, minimal purchases
4. **Tier 0** - Pointers to Klipper flashing resources

### Klipper Host Guides

The `klipper/` subfolder contains host-specific setup:
- `laptop-host.md` - Repurposed laptop running Klipper
- `rpi-3b-host.md` - Raspberry Pi 3B+ setup
- `zero-2w-host.md` - Raspberry Pi Zero 2W setup

## Guide Structure

Each tier guide follows this structure:
1. **Prerequisites** - What you need before starting
2. **Bill of Materials** - Tier-specific BOM
3. **Assembly** - Step-by-step with photos
4. **Wiring** - Electrical connections
5. **Klipper Config** - printer.cfg for the tier
6. **First Print** - Calibration and tuning

## Config-Driven Documentation

These guides are generated from templates using `config.py` settings via Quarto.
This ensures documentation stays in sync with the parametric CAD system.

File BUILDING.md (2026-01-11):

# 🛠️ Building Neo-Darwin Parts

This guide explains how to generate STL files from the parametric CAD files.

## Quick Start

Clone the repository and navigate to the CAD directory:

```bash
git clone https://github.com/neo-darwin-reprap/neo-darwin.git
cd neo-darwin/cad
```

Run the setup wizard:

```bash
./setup.sh
```

The wizard will guide you through:
1. Checking Python installation
2. Setting up virtual environment
3. Installing dependencies
4. Configuring your printer
5. Building all parts

## System Requirements

### Operating Systems
- **Linux**: Ubuntu, Fedora, Arch, Debian, etc.
- **macOS**: 10.14+ (Mojave or later)
- **Windows**: Via Git Bash, WSL, or PowerShell

### Software
- **Python 3.14+**: Required for running build123d scripts
  - [macOS](https://www.python.org/downloads/) - Download installer
  - [Linux](https://docs.python.org/3/installing/) - Use system packages
  - [Windows](https://www.python.org/downloads/) - Check "Add to PATH"

**Note:** Python 3.14+ is recommended for build123d 0.9.x compatibility

### Hardware
- ~500MB free disk space (for venv + dependencies)
- 4GB+ RAM recommended (build123d can be memory-intensive)

## Build Workflow

### Quick Decision Guide

| Situation | What to Run |
|---|---|
| New user, no setup yet | `./setup.sh` (everything) |
| Have config.py, want to build | `./build.sh build_all` |
| Want to change config | `./configure.py` then `./build.sh build_all` |
| Just updated repo, no config changes | `./build.sh build_all` |

### Option 1: First-Time Setup (Recommended)

**Best for:** New users, first time cloning the repo

```bash
cd cad
./setup.sh
```

**What happens:**
1. Detects your OS
2. Checks for Python 3.9+
3. Installs `uv` (optional, faster package manager)
4. Creates virtual environment (`.venv/`)
5. Installs dependencies (`build123d`, `numpy`)
6. Runs interactive configuration wizard (creates `config.py`)
7. Builds all parts

**After this:** You have a working setup with `config.py` created.

### Option 2: Just Build Parts

**Best for:** Already have `config.py` from previous build

```bash
cd cad
./build.sh build_all
```

**What happens:**
1. Checks for and activates `.venv/` automatically
2. Installs missing dependencies if needed
3. Builds all parts using your existing `config.py`

**Note:** If `config.py` doesn't exist, you'll get an error. Use `./configure.py` to create it.

### Option 3: Change Configuration

**Best for:** Want to modify printer settings

```bash
cd cad

# Just run configuration wizard (backs up existing config)
./configure.py

# Then rebuild with new settings
./build.sh build_all
```

**What happens:**
1. Asks configuration questions interactively
2. Backs up existing `config.py` to `config.py.backup`
3. Creates new `config.py` with your changes
4. `build.sh` will use the new config

### Option 4: Manual Control

**Best for:** Experienced users, want full control

```bash
cd cad

# Step 1: Create virtual environment (if needed)
python3 -m venv .venv

# Step 2: Activate environment
# macOS/Linux:
source .venv/bin/activate
# Windows (PowerShell):
.venv\Scripts\Activate.ps1

# Step 3: Install dependencies (if needed)
# Uses pyproject.toml (modern standard)
pip install -e .

# Step 4: Configure your printer (or edit config.py directly)
./configure.py

# Step 5: Build parts
./build.sh build_all
```

## Configuration

### When to Run Configuration Wizard

**Run `./configure.py` when:**
- First time setting up (creates new `config.py`)
- Want to change printer settings
- Switching hardware (different rods, hotend, etc.)

**Don't need to run when:**
- Just updated code from git
- Have `config.py` already set up
- Just want to rebuild parts

### Interactive Wizard

Run configuration wizard:

```bash
./configure.py
```

The wizard will ask about:
- **Build Volume**: X, Y, Z dimensions (mm)
- **M12 Rods**: Diameter and "lumpy factor" (0.2 for zinc, 0.5+ for galvanized)
- **Extruder**: Wade extruder settings
- **Hotend**: Type and mounting
- **Electronics**: Mainboard, Z-probe, CANbus

**Important:** This backs up your existing `config.py` to `config.py.backup`.

### Manual Configuration

Edit `config.py` directly:

```bash
vim config.py
# or
nano config.py
# or
code config.py
```

See `config.py.example` for all available options.

**Important:** `config.py` is ignored by git (your settings stay private).

## Building Parts

### Build All Parts

```bash
./build.sh build_all
```

The build script automatically:
- Discovers all Python parts in `parts/` directory
- Checks for and activates `.venv`
- Installs dependencies if not found

### Build Specific Parts

```bash
./build.sh build corner_front_left
```

### List Available Parts

```bash
./build.sh list
```

This will show all available parts, grouped by category:
- Frame corners, extruder parts, bed components, etc.

### Advanced: Test Mode

For testing with only a subset of parts:

```bash
TEST_MODE=true ./build.sh build_all
```

This uses only the corner motorized parts instead of discovering all files.

### Clean STL Directory

```bash
./build.sh clean
```

### View Help

```bash
./build.sh help
```

## What Happens When You Build

1. **Environment Check**: `build.sh` automatically detects and activates `.venv`
2. **Dependency Check**: Installs missing dependencies if needed
3. **Part Generation**: Runs Python CAD scripts to generate STLs
4. **Output**: STL files saved to `stl/` directory

## Troubleshooting

### Python Not Found

```bash
# macOS
brew install python@3.11

# Ubuntu/Debian
sudo apt install python3 python3-venv python3-pip

# Fedora
sudo dnf install python3 python3-venv python3-pip
```

### Build123d Import Error

```bash
# Make sure venv is activated
source .venv/bin/activate

# Reinstall dependencies (uses pyproject.toml)
pip install --force-reinstall -e .
```

### Out of Memory

If build123d runs out of RAM during part generation:
1. Close other applications
2. Add swap space (Linux)
3. Build parts individually instead of all at once

### Virtual Environment Issues

```bash
# Remove corrupted venv and recreate
rm -rf .venv
python3 -m venv .venv
source .venv/bin/activate
pip install -r requirements.txt
```

## Understanding the CAD System

### Parametric Design

Neo-Darwin uses **build123d**, a modern Python CAD library:
- **Code-based design**: All parts defined in Python scripts
- **Single source of truth**: `config.py` controls all dimensions
- **Easy customization**: Change config, rebuild all parts automatically

### Why Not Just Download STLs?

**Dynamic sizing**:
- Want larger build volume? Change `BUILD_VOLUME` in config
- Using salvaged 8mm rods instead of 10mm? Change `SMOOTH_ROD_DIA`
- Different hotend diameter? Update `GROOVEMOUNT_DIA`

**One command rebuilds everything**:
```bash
./configure.py
./build.sh build_all
```

No manually editing STL files or dealing with version mismatches!

### File Structure

```
cad/
├── parts/              # Python CAD scripts
│   └── corner_motorized.py
├── stl/               # Generated STL files (output)
├── config.py           # Your configuration (gitignored)
├── config.py.example   # Reference configuration
├── pyproject.toml    # Python dependencies (modern standard)
├── setup.sh          # Automated setup wizard
├── configure.py       # Interactive configuration
└── build.sh          # Part builder
```

## Next Steps

After building parts:

1. **Review STLs**: Open in slicer (Cura, PrusaSlicer, etc.)
2. **Prepare for Printing**: Check orientation, supports, infill
3. **Gather Hardware**: See [MANIFESTO.md](../MANIFESTO.md) for BOM
4. **Assembly Documentation**: Coming soon

## Contributing

Want to add new parts or improve existing ones?

1. **Design in build123d**: Create or modify Python scripts in `parts/`
2. **Update config**: Add new parameters to `config.py.example`
3. **Test**: Build and verify parts work correctly
4. **Document**: Add to this guide

## Getting Help

- **Issues**: [GitHub Issues](https://github.com/neo-darwin-reprap/neo-darwin/issues)
- **Discussions**: Coming soon
- **Documentation**: See `docs/` directory for detailed design docs

---

> **Remember**: This is a reference specification. If you want a printer, buy one. If you want the Red Pill, build this.

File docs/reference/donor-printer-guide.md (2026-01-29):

# Donor 3D Printer Compatibility Guide

This guide helps Amalgam builders identify which donor printers provide the most value and what to expect from each. Not all printers are equal donors—some provide smooth rods, others don't.

**Target release:** End of 2026
**Expected donor pricing:** ~$50 AUD per unit (secondhand market floor)

⚠️ **Cost Reality Check:** Before you start shopping, read [When NOT to Scavenge](#when-not-to-scavenge-enclosed--proprietary-printers) later in this guide. Amalgam makes financial sense only when donors are $100-150 each. Beyond that, commercial alternatives are competitive.

💡 **Budget for Contingencies:** Expect to spend **$80-150 on parts you can't scavenge** (M10 rods, M8 leadscrews, bearings, PSU, misc). See [Parts Sourcing & Replacement Guide](parts-sourcing-guide.md) for how to source these if a donor part fails or is damaged. **Total realistic budget: $250-380 AUD.**

## Quick Reference: Donor Tiers

### Fitness Categories (See ADR-026)

This section now uses **fitness tiers** based on bed size and Z-height (see ADR-026: Donor Fitness & Frame Constraints):

- **Tier 1 (Recommended):** 200–235mm bed, <280mm Z → Full support, no modifications
- **Tier 2 (Supported with notes):** 235–300mm bed, 280–400mm Z → Works with heatbed swap or heavier MDF
- **Tier 3 (Unsupported):** >300mm bed, >400mm Z → Not recommended, re-sell and buy Tier 1 donors

## Frame Paths by Donor Type

**Amalgam has three frame paths** (see ADR-025):

| Path | Component Match | Common Donors | Recommendation |
|---|---|---|---|
| **Darwin** | Two smooth-rod donors | Anet A8, Wanhao i3, Prusa clones | Primary—buy M10 rods (~$30-45) |
| **V-Core** | Two v-slot donors | Ender 3, CR-10, Aquila | Primary—zero-waste, recommended |
| **S-Core** | Mixed: extrusion + smooth-rod | Rare; mixed donor scenarios | Fallback only—usually avoid |

**S-Core is rare:** Most real-world printers are either all-smooth-rods (Darwin path) or all-v-slots (V-Core path). Extrusion + smooth-rod combinations are uncommon. If you have mixed donors, either:
1. Buy M10 rods and use Darwin path (cheaper, simpler)
2. Build S-Core if you have good extrusions available

---

### Tier 1: Rod-Bearing Donors (Recommended)

**Component compatibility:** Provide smooth rods AND bearings—the hardest parts to find cheap.
**Bed size:** 200–235mm. **Z-travel:** <280mm.

- **Anet A8 / A6** → Tier 1 ✅ (220×220, 240mm Z)
- **Prusa i3 clones** → Tier 1 ✅ (Geeetech, Tronxy X3, CTC; 200–220mm bed, ~260mm Z)
- **Anycubic i3 Mega** → Tier 1 ✅ (210×210, 200mm Z)
- **Prusa MK2 / MK2S** → Tier 1 ✅ (250×210, 210mm Z; premium quality)
- **Prusa MK3 / MK3S+** → Tier 1 ✅ (250×210, 210mm Z; premium quality, highest parts quality)

---

### Tier 1: V-Slot Donors (Recommended)

**Component compatibility:** V-slot motion system (no smooth rods), but excellent motors/electronics.
**Bed size:** 200–235mm. **Z-travel:** <280mm.

- **Creality Ender 3 / 3 Pro / 3 V2 / 3 S1** → Tier 1 ✅ (235×235, 250mm Z)
- **Voxelab Aquila** → Tier 1 ✅ (235×235, 250mm Z; Ender 3 clone)
- **Creality Ender 5 / 5 Pro** → **See Tier 3 note** ⓘ (Has own dedicated projects like Mercury One)
- **Elegoo Neptune series** → Tier 1 ✅ (235×235, 250mm Z; Ender 3 competitor)

---

### Tier 2: Larger Bed Donors (Supported with Mitigation)

**Bed size:** 235–300mm. **Z-travel:** 280–400mm. **Note:** Recommend heatbed swap (to 220×220) or heavier MDF base.

- **Creality CR-10 / CR-10S** → Tier 2 ⚠️ (300×300, 400mm Z)
- **Artillery Sidewinder X1 / Genius** → Tier 2 ⚠️ (300×300, 360mm Z)

*See ADR-026 for heatbed swap guide and MDF thickness recommendations.*

---

### Tier 3: Specialty/Limited Donors (Not Recommended)

Limited usefulness due to size, proprietary parts, or unsupported geometry:

- **Prusa Mini / Mini+** → Limited (180×180, too small; good for SuperPINDA probe scavenge)
- **Ender 2** → Limited (165×165, too small)
- **Ender 5 / Ender 5 Pro** → **Has own project** ⓘ (Mercury One and other Ender 5 conversions exist; those communities are more appropriate)
- **Tronxy models (especially X5S, large format)** → **Has own projects** ⓘ (Tronxy community has dedicated upgrade paths; Amalgam not optimized for Tronxy geometry)
- **Delta printers** → Unsupported (wrong geometry, can't use components)
- **Resin printers** → Unsupported (nothing reusable)
- **Tevo Spider (large models)** → Tier 3 ❌ (500×500, too large; unsupported)
- **Custom/modified printers** → Varies (too many unknowns)

---

## Detailed Donor Breakdown

### Anet A8 / A6

**Fitness Tier:** ✅ **Tier 1 (Recommended)**
**Bed:** 220×220mm | **Z-travel:** 240mm | **Frame path:** Darwin (primary)

**Why it's excellent:** Millions sold, often "broken" (usually just needs firmware update or new MOSFET). 220×220mm bed matches Amalgam reference spec exactly. Perfect fit for Darwin frame path. Steel frame is not useful for Amalgam, but motion components are excellent.

| Component | Spec | Amalgam Use | Notes |
|---|---|---|---|
| **Smooth rods** | 6× 8mm (various lengths) | ✅ Direct use | Check for wear/rust |
| **Linear bearings** | 6× LM8UU | ✅ Direct use | Clean and regrease |
| **NEMA17 motors** | 5× (X, Y, Z×2, E) | ✅ Direct use | Standard 1.8° steppers |
| **Heated bed** | 220×220mm, 12V | ✅ Reference spec size | May need rewire for 24V |
| **Power supply** | 12V 20A (240W) | ⚠️ Upgrade recommended | Underpowered for 24V system |
| **Mainboard** | Anet V1.x (4 drivers) | ✅ Tier 2 MCU | Flash Klipper firmware |
| **Lead screw** | 2× T8 threaded rod | ✅ Z-axis | Check for wobble |
| **Endstops** | 3× mechanical switches | ✅ Direct use | Standard microswitches |
| **Hotend** | Anet A8 (E3D V6 clone) | ⚠️ Replace nozzle | Cheap clone, works |
| **Extruder** | MK8 style | ❌ Replace with Pitan | Not geared |
| **Wiring** | Various | ✅ Reuse connectors | JST-XH, Dupont, etc. |
| **Belts** | GT2 6mm | ✅ Direct use | Check for wear |
| **Pulleys** | GT2 16T/20T | ✅ Direct use | |
| **Hardware** | M3, M4, M5 bolts/nuts | ✅ Parts bin | Metric standard |

**Yield from 2× Anet A8:**
- 12× smooth rods (need 8)
- 12× LM8UU bearings (need 16, buy 4 more or use LM8LUU)
- 10× NEMA17 motors (need 7)
- 2× heated beds (use better one)
- 2× mainboards (Tier 2 dual-MCU)
- 4× lead screws (need 3)
- 6× endstops (need 6)

---

### Prusa i3 Clones (Geeetech, Tronxy X3, Wanhao i3, Coolcoin Create, CTC, Alunar, etc.)

**Fitness Tier:** ✅ **Tier 1 (Recommended)**
**Bed:** 200–220mm | **Z-travel:** 260mm (typical) | **Frame path:** Darwin (primary)
**Frame type:** Steel rod frame (like Anet A8, not extrusion-based)

**Why it's good:** Direct descendants of original RepRap design. Rod-based steel frames are compatible with Darwin/M10 path philosophy. Build quality varies by brand. All Tier 1 compatible. Steel frame not useful for Amalgam, but smooth rods and motors are excellent.

| Component | Spec | Amalgam Use | Notes |
|---|---|---|---|
| **Smooth rods** | 6× 8mm | ✅ Direct use | Quality varies by brand |
| **Linear bearings** | 6× LM8UU | ✅ Direct use | Often cheap quality; use IGUS if worn |
| **NEMA17 motors** | 4-5× | ✅ Direct use | Standard steppers |
| **Heated bed** | 200–220mm | ✅ Works well | Slightly smaller than reference; acceptable |
| **Steel frame** | Rod-based structure | ⚠️ Not reused | Can't transfer to Amalgam box frame (use M10 rods instead) |
| **Power supply** | 12V | ⚠️ Upgrade | Consider 24V for dual MCU |
| **Mainboard** | Various (4 drivers) | ✅ Tier 2 MCU | Check MCU (ATMEGA, STM32) compatibility |
| **Lead screw** | 2× T8 | ✅ Z-axis | Inspect for wobble |

**Watch out for:**
- **Tronxy X3:** Good donor, classic i3 clone (220×220, 260mm Z) ✅ Tier 1
- **Wanhao i3:** Good donor, similar to Anet A8 (220×220, 240mm Z) ✅ Tier 1
- **Coolcoin Create:** Similar to Wanhao/Anet (210×210 typical, 260mm Z) ✅ Tier 1
- **Tronxy X5S / large format models:** **See Tier 3 note** ⓘ (Have their own project communities)
- **Geeetech i3:** Some use acrylic frame (useless), but rod-based ones are Tier 1
- **CTC/Alunar:** Cheapest clones, rod quality varies; inspect carefully before purchase

---

### Anycubic i3 Mega / Mega S

**Fitness Tier:** ✅ **Tier 1 (Recommended)**
**Bed:** 210×210mm | **Z-travel:** 200mm | **Frame path:** Darwin (primary)

**Why it's good:** Better build quality than Anet A8, still has smooth rods and a steel frame. Rod-based design like Anet A8. Excellent components for Darwin path. Steel frame not useful for Amalgam, but motion components are premium quality.

| Component | Spec | Amalgam Use | Notes |
|---|---|---|---|
| **Smooth rods** | 6× 8mm | ✅ Direct use | Good quality, hardened steel |
| **Linear bearings** | 6× LM8UU | ✅ Direct use | Branded bearings, excellent quality |
| **NEMA17 motors** | 5× | ✅ Direct use | Higher quality than Anet |
| **Heated bed** | 210×210mm (Ultrabase) | ✅ Works | Ultrabase PEI surface is excellent |
| **Power supply** | 12V 20A | ⚠️ Upgrade | Consider 24V for efficiency |
| **Mainboard** | Trigorilla (4 drivers) | ✅ Tier 2 MCU | ATMEGA2560 based, very capable |
| **Lead screw** | 2× T8 | ✅ Z-axis | Good quality |
| **Steel frame** | Structural steel | ⚠️ Not useful | Not aluminum extrusion; discard or repurpose |
| **Touchscreen** | Anycubic TFT | ❌ Not useful | Proprietary, leave behind |

**Frame note:** i3 Mega uses a **steel frame** (not aluminum extrusions), similar to Anet A8. The frame itself won't transfer to an Amalgam build, but all the motion and electronics components are excellent.

---

### Prusa MK2 / MK2S / MK3 / MK3S+

**Fitness Tier:** ⚠️ **Tier 1 Components, But Frame Not Easily Adaptable**
**Recommendation:** **Just add Klipper, don't dismantle.** Prusa machines have excellent structural design that's hard to repurpose; not ideal Amalgam donors despite component quality.

**Why not ideal as donors:** Prusa's CNC aluminum frame (especially MK3) is not a box-frame design. Disassembling and repurposing these machines would destroy their most valuable feature—a well-engineered, integrated structure. Better to upgrade with Klipper than to scavenge.

**Component Quality (If You Must Scavenge):**

| Component | Spec | Amalgam Use | Notes |
|---|---|---|---|
| **Smooth rods** (MK2/3) | 6× 8mm (hardened) | ✅ Excellent | Premium hardened steel |
| **Linear bearings** | 3× LM8UU + 3× LM8LUU | ✅ Direct use | Top-tier bearings, mix sizes |
| **NEMA17 motors** | 5× | ✅ Direct use | Genuine LDO or Moons motors |
| **Heated bed** (MK2/3) | 250×210mm (MK52) | ✅ Works | Magnetic PEI, but rectangular |
| **Power supply** (MK3) | 24V (15A+) | ✅ Direct use | Ideal voltage |
| **Mainboard** (MK3) | Einsy (5 drivers, TMC) | ✅ Excellent | Has TMC2130 steppers |
| **PINDA probe** (MK3S+) | SuperPINDA | ✅ Reference spec | Metal-detecting, ideal |
| **Frame** (MK2/3) | CNC aluminum | ❌ Not useful | Integrated design; can't adapt to Amalgam box frame |

**Better use:** Buy a broken MK3 (~$150), flash Klipper firmware, keep it as a working printer. You gain a known-good machine + reference quality components without the scavenge overhead.

**MK2 Note:** Uses threaded rod frame (not extrusions), but still integrated design—harder to repurpose than Anet A8.

---

### Creality Ender 3 / 3 Pro / 3 V2 / 3 S1

**Fitness Tier:** ✅ **Tier 1 (Recommended)**
**Bed:** 235×235mm | **Z-travel:** 250mm | **Frame path:** V-Core (recommended) or Darwin (requires buying rods)

**Why it's excellent:** Best-selling printer ever. Cheap and everywhere. **With ADR-025 Multi-Frame Architecture, Ender 3 is now fully supported via V-Core path—use the aluminum extrusions and V-slot rails directly.** No rod purchase needed if using V-Core.

| Component | Spec | Amalgam Use | Notes |
|---|---|---|---|
| **V-slot extrusions** | 2020/2040 frame | ✅ V-Core path | Reuse as frame structure |
| **V-slot rollers** | 4× wheels per carriage | ✅ V-Core motion | Scavenged motion system, zero waste |
| **NEMA17 motors** | 4× (X, Y, Z, E) | ✅ Direct use | Need 2 donors for 7+ total |
| **Heated bed** | 235×235mm, 24V | ✅ Good size | Slightly larger than 220 reference; works |
| **Power supply** | 24V 30A typical | ✅ Direct use | Ideal for 24V system |
| **Mainboard** | Creality 4.2.x (4 drivers) | ✅ Tier 2 MCU | STM32/GD32 based, good quality |
| **Lead screw** | 1× T8 | ⚠️ Need 3 total | Only one per printer; buy one more |
| **Endstops** | 2-3× mechanical | ✅ Direct use | Standard microswitches |
| **Hotend** | MK8/Creality | ⚠️ Replace | Not E3D compatible; use E3D V6 |
| **Extruder** | Bowden or direct | ❌ Replace | Replace with Pitan (all paths) |
| **Belts** | GT2 6mm | ✅ Direct use | Check for wear |
| **Smooth rods** | ❌ None | ✅ Not needed for V-Core | Darwin path would need to buy |

**Two Ender 3 Donors (V-Core Path):**
- ✅ Frame: 2× full extrusion sets (use better condition one or combine)
- ✅ Motion: All V-slot wheels scavenged (zero additional cost)
- ✅ Motors: 8× NEMA17 (need 7, one spare)
- ✅ Beds: 2× 235×235 (use one)
- ✅ Electronics: 2× Creality mainboards (dual-MCU setup)
- ✅ PSU: 2× 24V (use better one)
- ⚠️ Lead screws: 2× T8 (need 3, buy 1 more ~$5–8)
- **Total new parts needed:** ~$8–12 (just one lead screw!)

---

### Creality CR-10 / CR-10S / CR-10 V2

**Fitness Tier:** ⚠️ **Tier 2 (Supported with Mitigation)**
**Bed:** 300×300mm | **Z-travel:** 400mm | **Frame path:** V-Core (recommended) | **Mitigation:** Heatbed swap to 220×220 (recommended) OR heavier MDF base

**Why consider it:** Larger format with dual Z motors. V-slot motion system. **Note:** See ADR-026 for fitness constraints. The large bed size and Z-height require either heatbed swap or heavier MDF damping for stability.

| Component | Spec | Amalgam Use | Notes |
|---|---|---|---|
| **V-slot extrusions** | 2020/2040 frame | ✅ V-Core path | Good stiffness for larger format |
| **V-slot rollers** | 4-6× per carriage | ✅ V-Core motion | Scavenged system works |
| **NEMA17 motors** | 5× (dual Z motors!) | ✅ Direct use | Extra Z motor is bonus ✅ |
| **Heated bed** | 300×300mm | ⚠️ Swap recommended | Too large; recommend swap to 220×220 ($25–35) |
| **Power supply** | 24V 30A (typical) | ✅ Direct use | Good quality PSU |
| **Mainboard** | Creality 4.2.x (4 drivers) | ✅ Tier 2 MCU | STM32/GD32 based |
| **Lead screw** | 2× T8 | ✅ Z-axis | Already has dual Z, excellent |
| **Endstops** | 3× mechanical | ✅ Direct use | Standard microswitches |
| **Hotend** | MK8/Creality | ⚠️ Replace | Not E3D; replace with E3D V6 |
| **Extruder** | Bowden | ❌ Replace | Replace with Pitan |
| **Belts** | GT2 6mm (wider available) | ✅ Direct use | Check condition |

**Mitigation Options (Choose One):**

1. **Option A (Recommended):** Swap heatbed to 220×220
   - Cost: $25–35 (MK3 Dual Power or generic)
   - Result: Frame becomes 220×220mm, Z-height unchanged (~400mm)
   - Benefit: Perfect frame size, only moderate Z-height for Tier 2
   - Process: 4× M3 bolts, rewire heating element

2. **Option B:** Use heavier MDF base (50–60mm instead of 40mm)
   - Cost: ~$10 extra material
   - Result: Improved mass damping for larger bed
   - Drawback: Heavier final machine, may need stronger Z-motors

3. **Option C:** Not Recommended: Use as-is (300×300 on standard MDF)
   - Risk: Nozzle compliance issues, bed leveling instability
   - Outcome: Tier 3 unsupported deviation

**Why Tier 2:** CR-10's 400mm Z-height is at the boundary of stability. With heatbed swap, it becomes an excellent Tier 1 candidate.

---

### Voxelab Aquila

**Fitness Tier:** ✅ **Tier 1 (Recommended)**
**Bed:** 235×235mm | **Z-travel:** 250mm | **Frame path:** V-Core (primary) or Darwin (with rod purchase)

**Essentially an Ender 3 clone.** Nearly identical compatibility, same V-Core path benefits (no rod purchase needed). Scavenged motion system is zero-waste.

---

### Artillery Sidewinder X1 / Genius

**Fitness Tier:** ⚠️ **Tier 2 (Supported with Mitigation)**
**Bed:** 300×300mm | **Z-travel:** 360mm | **Frame path:** V-Core (recommended) | **Mitigation:** Heatbed swap to 220×220 (recommended)

**Why consider it:** Direct drive, excellent PSU, good dual Z motors. V-slot motion. Similar to CR-10 in size constraints—see ADR-026 for fitness details.

| Component | Spec | Amalgam Use | Notes |
|---|---|---|---|
| **V-slot extrusions** | 2020/2040 frame | ✅ V-Core path | Good stiffness |
| **V-slot rollers** | 4-6× per carriage | ✅ V-Core motion | Scavenged system |
| **NEMA17 motors** | 5× | ✅ Direct use | Dual Z standard (bonus) |
| **Heated bed** | 300×300mm | ⚠️ Swap recommended | Too large; recommend swap to 220×220 ($25–35) |
| **Power supply** | 24V 30A | ✅ Direct use | Excellent quality PSU, premium feature |
| **Mainboard** | Mainboard K | ✅ Tier 2 MCU | STM32 based, capable |
| **Direct drive** | Titan clone | ⚠️ Parts for bin | Gears/springs useful; replace nozzle |

**Mitigation:** Same as CR-10—recommend heatbed swap to 220×220. With swap, becomes excellent Tier 1 candidate.

---

### Elegoo Neptune Series

**Fitness Tier:** ✅ **Tier 1 (Recommended)**
**Bed:** 235×235mm | **Z-travel:** 250mm | **Frame path:** V-Core (primary)

**Ender 3 competitor.** Similar to Ender 3 in what's reusable—V-slot motion system, zero rod purchase needed. V-Core path highly recommended.

---

### Prusa Mini / Mini+

**Fitness Tier:** ❌ **Tier 3 (Limited, Not Recommended as Primary Donor)**
**Bed:** 180×180mm | **Z-travel:** 180mm | **Issue:** Bed too small, rods too short for standard Amalgam specs.

**Limited donor value:** Below Tier 1 minimum (200×200mm bed). Consider Prusa Mini as **secondary** donor or parts scavenge only.

| Component | Spec | Amalgam Use | Notes |
|---|---|---|---|
| **Smooth rods** | 4× 8mm (short) | ⚠️ Too short | Cantilever design, not 220mm+ length |
| **Heated bed** | 180×180mm | ❌ Too small | Below 200mm minimum for Tier 1 |
| **NEMA17 motors** | 3× (no Y) | ⚠️ Cantilever | Mini uses gantry-mounted Z |
| **Mainboard** | Buddy (5 drivers, TMC) | ✅ Good MCU | STM32, Klipper compatible; save for electronics |
| **SuperPINDA** | Yes | ✅ Excellent | Z-probe is reference-spec quality; valuable |

**Best use:** Scavenge the SuperPINDA (reference spec z-probe) and Buddy mainboard. Use 4× short rods for parts bin, not motion. Combine with a Tier 1 donor (e.g., Ender 3) for complete build.

---

## What Else to Scavenge

Beyond the major components, don't overlook:

### Hardware (Nuts, Bolts, Washers)
- **M3 bolts** (various lengths): Frame, brackets, mounts
- **M3 nuts** (standard and nylock): Most printed parts
- **M3 washers**: Bed leveling, spacing
- **M4/M5 bolts**: Bed mounting, larger brackets
- **Heatset inserts**: If donor used them

### Wiring and Connectors
- **JST-XH connectors**: Motor, endstop, thermistor
- **Dupont connectors**: Headers, jumpers
- **Silicone wire**: 18-22 AWG for heated bed, hotend
- **Cable chains**: If donor had them
- **Zip ties**: Always useful

### Microswitches and Sensors
- **Mechanical endstops**: 3× minimum for XYZ homing
- **Optical endstops**: High precision alternative
- **Thermistors**: 100K NTC (bed, hotend)
- **Fans**: 4010, 4020, 5015 blowers

### Belts and Pulleys
- **GT2 belts**: 6mm width, check for wear/cracks
- **GT2 pulleys**: 16T or 20T, 5mm bore
- **Idler pulleys**: Smooth or toothed
- **Belt tensioners**: Springs, adjustment screws

### Misc Useful Parts
- **PTFE tube**: Bowden tube (4mm OD, 2mm ID)
- **Couplers**: Pneumatic fittings for PTFE
- **Springs**: Bed leveling springs
- **Thumbwheels**: Bed adjustment knobs
- **Heatsinks**: Motor, driver cooling

---

## Recommended Donor Combinations

All combinations below use **Tier 1 donors** (200–235mm beds, <280mm Z). For Tier 2 donors (CR-10, Artillery), see ADR-026 mitigation options.

⚠️ **Note:** These are best-case costs assuming all donor parts are usable. **Budget an additional $80-150 for parts you'll likely source** (M10 rods, M8 leadscrews, replacement bearings, PSU, etc.). See [Parts Sourcing & Replacement Guide](parts-sourcing-guide.md) if a donor part fails or is damaged. **Realistic total budget: $250-380 AUD.**

### Best Value: 2× Anet A8 (or Prusa i3 Clones) — Darwin Path
**Fitness:** ✅ Tier 1 + Tier 1 → **Fully Supported**
- **Total cost:** ~$100 AUD (two donors)
- **Frame path:** Darwin (M10 rods) + MDF base
- **Motion system:** Dual 8mm smooth rods (scavenged)
- **Heatbed size:** 220×220mm (reference spec)
- **Electronics:** Dual-MCU Klipper
- **New parts required:** M10 threaded rods (~$30–45), MDF (~$15–20)
- **Total Amalgam build:** ~$160–190 AUD
- **Why excellent:** Zero need to buy motion parts, perfect bed size, RepRap heritage

### Most Common: 2× Ender 3 — V-Core Path
**Fitness:** ✅ Tier 1 + Tier 1 → **Fully Supported (with ADR-025)**
- **Total cost:** ~$100 AUD (two donors)
- **Frame path:** V-Core (extrusions + V-slots)
- **Motion system:** V-slot wheels (scavenged, zero-waste)
- **Heatbed size:** 235×235mm (within Tier 1, works great)
- **Electronics:** Dual-MCU Klipper
- **New parts required:** 1× lead screw (~$8), MDF (~$15–20)
- **Total Amalgam build:** ~$160–180 AUD
- **Why excellent:** Zero rod/bearing purchase, perfect waste-free scavenging, 24V power supply included

### Mixed Donor: Ender 3 + Anet A8 — Flexible Hybrid
**Fitness:** ✅ Tier 1 + Tier 1 → **Fully Supported**
- **Total cost:** ~$100 AUD
- **Frame path:** Darwin (use Anet's rod-based wisdom)
- **Motion system:** 8mm smooth rods (from Anet, scavenged)
- **Heatbed:** Ender 3's 235×235 or Anet's 220×220 (both work)
- **Electronics:** Both mainboards contribute to Tier 2 dual-MCU
- **Advantage:** Ender 3's 24V PSU, Anet's proven rods
- **Total:** ~$160–190 AUD
- **Why good:** Best of both worlds; no compromise on any component

### Premium Path: Prusa MK3 + Ender 3 — Dual-MCU Overkill (Optional)
**Fitness:** ✅ Tier 1 + Tier 1 → **Fully Supported**
- **Total cost:** ~$200+ AUD (if you find an MK3 cheap)
- **Frame path:** Darwin or V-Core (your choice)
- **Heatbed:** Prusa's 250×210 (rectangular, excellent)
- **Electronics:** Einsy (5-driver TMC) + Creality board = overkill, but works
- **Bonus:** SuperPINDA reference-spec probe, LM8LUU premium bearings, 24V PSU
- **Why premium:** Highest quality scavenged parts, but hard to find MK3 cheap
- **Recommendation:** Only pursue if MK3 <$120. Otherwise, better to buy MK3 electronics new.

### Tier 2 Upgrade Path: CR-10 + Ender 3 (with Heatbed Swap) — V-Core with Mitigation
**Fitness:** ⚠️ Tier 2 + Tier 1 → **Supported with Heatbed Swap**
- **Total cost:** ~$120 AUD (two donors) + $25–35 (heatbed swap)
- **Frame path:** V-Core
- **Motion system:** V-slot wheels (scavenged from both)
- **Heatbed:** Swap CR-10's 300×300 to 220×220 (MK3 Dual Power ~$25–35)
- **Electronics:** Dual-MCU (two Creality boards)
- **New parts:** Lead screw (~$8) + heatbed (~$25) + MDF (~$15)
- **Total Amalgam build:** ~$180–210 AUD
- **Why consider it:** CR-10's dual Z motors and better PSU; workable with mitigation
- **Note:** Follow ADR-026 for heatbed swap process and MDF damping requirements

---

## Understanding Fitness Tiers (ADR-026)

This guide uses **fitness tiers** to help you assess donor suitability. See **ADR-026: Donor Fitness & Frame Constraints** for the full physics and rationale.

**Quick Summary:**

| Tier | Bed Size | Z-Height | Support Level | Mitigation |
|---|---|---|---|---|
| **Tier 1 ✅** | 200–235mm | <280mm | Full support | None needed |
| **Tier 2 ⚠️** | 235–300mm | 280–400mm | Supported | Heatbed swap or heavier MDF |
| **Tier 3 ❌** | >300mm | >400mm | Not recommended | Buy different donor pair |

**Examples:**
- Anet A8 (220×220, 240mm Z) → **Tier 1** ✅
- Ender 3 (235×235, 250mm Z) → **Tier 1** ✅
- CR-10 (300×300, 400mm Z) → **Tier 2** ⚠️ (swap bed or use heavier MDF)
- Tevo Spider (500×500, 500mm Z) → **Tier 3** ❌ (don't use)

**Why it matters:** Larger beds and taller gantries reduce system stiffness. MDF base provides damping, but there are physical limits. Tier 2 donors work great with simple mitigations (heatbed swap = $25–35). Tier 3 is beyond the scavenger philosophy—sell it and buy a matched Tier 1 pair.

---

## Where to Find Donors

### Best Sources (Australia)
1. **Facebook Marketplace** - Search "broken 3D printer", "Ender 3 parts", "Anet A8"
2. **Gumtree** - Similar to Marketplace
3. **University/TAFE surplus** - Often bulk lots
4. **Makerspace clearouts** - Ask your local space
5. **eBay** - For specific parts, rarely whole printers cheap

### Hunting Tips
- **Post "wanted" ads** - "Looking for broken 3D printers, any condition, $30-50"
- **Be patient** - $150 listings will eventually drop
- **Lot deals** - "Take all 3 for $100" is common
- **Condition doesn't matter** - "Won't heat" or "won't home" = easy fix
- **Inspect rods** - Roll on glass to check for bends

### What to Avoid
- **Resin printers** - Nothing reusable
- **Delta printers** - Wrong geometry, weird steppers
- **Heavily modified** - Missing stock parts
- **Fire damage** - Wiring compromised
- **"Upgraded" expensive** - Paying for someone else's mods

---

## Pre-Teardown Checklist

Before dismantling, verify:

1. **Power on test** (if safe)
   - Motors move? → Good steppers
   - Bed heats? → Good heater, thermistor
   - Home works? → Good endstops

2. **Rod quality check**
   - Roll on glass/mirror
   - Check for rust, scoring, wear marks
   - Measure diameter (should be 8.00 ±0.02mm)

3. **Motor test**
   - Spin by hand - should feel smooth with detents
   - Check for grinding or binding

4. **Bearing test** (if accessible)
   - Slide on rod - should be smooth
   - No grinding, clicking, or excessive play

5. **Document wiring**
   - Photo before disconnecting
   - Label connectors with tape

---

## When NOT to Scavenge: Enclosed & Proprietary Printers

At a certain price point, **dismantling an old printer costs more than its parts are worth**. These machines are better off Klipperized whole or skipped entirely.

### Cost Threshold Reality

**Amalgam makes financial sense only if donors are reasonably priced.** Before you commit:

| Donor Cost | Recommendation |
|---|---|
| **$100-150 each** | ✅ Good range—Amalgam build: $200-300 total |
| **$150-200 each** | ⚠️ Borderline—reconsider your strategy |
| **>$200 each** | ❌ Just buy **Bambu A1 Mini** (~$180) or **Ender 3 V3 SE** (~$150) new |

**Your goal:** Save money by scavenging. If you're paying premium prices, you've already lost.

### Enclosed Box-Frame Printers: Just Klipperize, Don't Dismantle

These machines are **better upgraded whole than dismantled**:

#### Anycubic 4Max Pro 2.0
- **Secondhand price:** ~$250 AUD
- **Why keep it whole?** Already enclosed, good frame, dual Z built-in, TMC drivers
- **What to do:** Flash Klipper firmware; use as-is
- **Benefit:** Working closed-loop system + Klipper's best features
- **Dismantle cost:** Labor > parts value at this price

#### XYZ da Vinci (All Models: Pro, Jr., Mini)
- **Mainboard:** Proprietary; reverse engineering required for Klipper
- **Hotend:** Proprietary cartridge system; incompatible with E3D V6
- **Bed system:** Single-point support (sag issues, like Ender 5)
- **Frame:** Integrated design (can't reuse cleanly)
- **Donor value:** Low; locked-down ecosystem
- **What to do:** Keep and upgrade with Klipper if you want it; don't dismantle for parts
- **Reality:** Parts salvage value << disassembly effort

#### FlashForge (Creator, Pro, Adventure)
- **Everything:** Proprietary firmware, mainboard, hotend connectors, bed system
- **Integration:** Tightly integrated; difficult disassembly
- **Donor value:** Very low
- **Compatibility:** None with standard Klipper builds
- **What to do:** Keep as-is or recycle; not a practical Amalgam source

### Scavenging Strategy: How to Avoid Wasting Money

**Before you buy an old printer to scavenge:**

1. **Identify two matched donors** (both smooth-rod OR both v-slot)
   - Example: Two Anet A8s, or Two Ender 3s
   - Avoid mixing (requires extra purchases)

2. **Calculate total cost:**
   - Donor 1: $_____
   - Donor 2: $_____
   - MDF base: $15-20
   - Frame material (M10 rods if Darwin, $0 if V-Core): $0-45
   - Misc (bolts, wires): ~$40
   - **Total: $____**

3. **Apply the rule:**
   - **If total < $280 AUD:** ✅ Good scavenger territory (matched donors)
   - **If total $280-300 AUD:** ⚠️ At parity with Bambu A1 Mini; reconsider
   - **If total > $300 AUD:** ❌ Just buy a new commercial printer instead

4. **If you find one printer, but no second match:**
   - Don't overpay for a second one just to avoid buying M10 rods
   - Buy M10 rods (~$35) and pick *any* other Darwin-compatible donor
   - Or buy a different matched pair

### The Enclosed Printer Problem in a Nutshell

**Enclosed machines gain little from Amalgam disassembly:**

| Issue | Impact |
|---|---|
| Proprietary mainboards | Don't work with standard Klipper setups; reverse engineering required |
| Integrated frame + electronics | Can't reuse either cleanly; disassembly is destructive |
| Non-standard hotends | Require custom mounts; incompatible with E3D V6 reference spec |
| Proprietary bed systems | Can't adapt to Amalgam's Triple-Z leveling |
| Difficult disassembly | More labor than the salvaged parts are worth |

---

**Bottom line:** Amalgam is for **matching donor pairs** scavenged in the **$100-150 each range**. Enclosed, proprietary machines at $200+ are better left alone, upgraded whole with Klipper, or skipped entirely. Don't pay premium prices for parts that will cost you premium labor to extract.

---

## What If a Donor Part Fails?

Sometimes you'll discover mid-build that a PSU is dead, a leadscrew is bent, or bearings are worn.

**See [Parts Sourcing & Replacement Guide](parts-sourcing-guide.md)** for:
- How to source replacements from AliExpress, Temu, eBay
- How to spot counterfeits and avoid duds
- Budget planning and decision tree
- Common pitfalls (wrong pitch leadscrew, fake bearings, etc.)

---

## References

- **ADR-026**: Donor Fitness & Frame Constraints (bed size, Z-height, stability physics)
- **ADR-025**: Multi-Frame Architecture (Darwin, S-Core, V-Core paths)
- **ADR-021**: Dual-Rod Motion System (rod requirements)
- **ADR-022**: Linear Bearing Selection (bearing options, IGUS path)
- **ADR-024**: Heated Bed Size Selection (bed compatibility)
- **ADR-012**: Mainboard Architecture (dual-MCU configuration)
- **docs/reference/ai-conversations/scavenger-guide.md**: Office equipment scavenging

---

*"The code handles the permutations; the iron handles the quality."*

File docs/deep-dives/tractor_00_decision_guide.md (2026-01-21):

# Neo-Darwin: Tier 0 Decision Guide

## Before You Start: An Honest Conversation

Neo-Darwin is a tribute to the original RepRap Darwin printer—a "Tractor with a Racecar Brain" built from scavenged parts, M10 threaded rods, and the Klipper firmware. It prioritizes understanding, repairability, and the satisfaction of building something with your hands.

**But it's not for everyone.**

This guide will help you honestly assess whether Neo-Darwin is the right project for you, or whether you'd be better served buying a commercial printer.

---

## The 2025 Reality Check

The 3D printer market has fundamentally changed since the RepRap era:

| Era | DIY Build Cost | Best Commercial Option | DIY Advantage |
|-----|---|---|---|
| 2007 (Darwin) | ~$1,000 | $10,000+ (Stratasys) | Only option for hobbyists |
| 2012 (Mendel i2) | ~$500 | $2,000+ (MakerBot) | Massive cost savings |
| 2018 (Ender era) | ~$300 | $200 (Ender 3) | Learning experience only |
| 2025 (Today) | ~$200+ | $180 (Ender 3 V3 SE) | **None** (economically) |

**The brutal truth:** If you need to *purchase* most of the parts for Neo-Darwin, you cannot compete with Chinese manufacturing on cost, and increasingly not on quality either.

### The New Landscape

Budget options that didn't exist a few years ago:

| Printer | Price | Quality | Speed | Notes |
|---|---|---|---|---|
| Creality Ender 3 V3 SE | ~$180 | Good | Moderate | Hard to beat on value |
| Creality Ender 3 V3 KE | ~$250 | Good | Fast | Klipper pre-installed |
| Elegoo Neptune 4 | ~$200 | Good | Fast | Klipper-based |
| QIDI X-Smart 3 | ~$350 | Very Good | Fast | Enclosed, CoreXY |
| Bambu Lab A1 Mini | ~$250 | Excellent | Very Fast | "It just works" |
| Bambu Lab A1 | ~$400 | Excellent | Very Fast | Larger build volume |

**Even Creality and QIDI are approaching Bambu Lab quality** in their newer models. The gap is closing rapidly.

### The Open vs. Closed Ecosystem Question

Before recommending any printer, we need to address something important: **not all printers are created equal in terms of openness**.

#### Bambu Lab: The Elephant in the Room

Bambu Lab makes excellent printers. They "just work." But there's a trade-off:

| Aspect | Bambu Lab Approach | Why It Matters |
|---|---|---|
| Firmware | Closed source, encrypted | You can't modify or fully understand it |
| Cloud dependency | Optional but pushed | Some features require Bambu Cloud account |
| Repair parts | Proprietary components | Limited third-party options |
| Modifications | Discouraged, may void warranty | Less hackable than open alternatives |
| Data collection | Telemetry enabled by default | Privacy considerations |
| Longevity | Depends on company support | If Bambu disappears, so does support |

**This isn't necessarily bad** — many users happily trade openness for convenience. The printer works, prints are excellent, and they don't care about modifying it.

**But if you value:**
- Right to repair
- Understanding your tools
- Privacy and data ownership
- Long-term independence from any company
- The maker/hacker ethos

**Then Bambu's closed ecosystem may not align with your values**, regardless of print quality.

#### Open Alternatives

| Printer | Openness | Trade-off |
|---|---|---|
| Prusa (Original) | Fully open source hardware & firmware | Slower than Bambu, higher price |
| Voron (Self-sourced) | 100% open, community-driven | You build it yourself |
| Creality (Klipper models) | Open firmware, mixed hardware | Quality inconsistent |
| Elegoo/QIDI | Mostly open (Klipper-based) | Some proprietary elements |
| **Neo-Darwin** | 100% open, scavenger-friendly | You build it yourself |

**Our stance:** We mention Bambu Lab because they make genuinely good printers, and honesty requires acknowledging that. But we also believe you should know what you're trading away. **Make an informed choice.**

---

### The Voron Option: High-End DIY

If you want to *build* a printer but also want **speed, precision, and reliability**, there's another path: **Voron**.

#### What is Voron?

Voron is a family of open-source, self-sourced CoreXY printers designed by enthusiasts for enthusiasts. They're the "high-end DIY" option:

| Voron Model | Build Volume | Style | Typical Cost |
|---|---|---|---|
| Voron 0.2 | 120×120×120 | Tiny, enclosed | $400-600 |
| Voron Trident | 250-350mm³ | Enclosed, triple-Z | $1,000-1,500 |
| Voron 2.4 | 250-350mm³ | Enclosed, flying gantry | $1,200-1,800 |

#### Voron vs. Neo-Darwin

| Factor | Voron | Neo-Darwin |
|---|---|---|
| **Goal** | Best possible DIY printer | Learn, scavenge, understand |
| **Frame** | Aluminum extrusion (purchased) | M10 threaded rod (hardware store) |
| **Motion** | Linear rails (MGN9/12) | Smooth rods (scavenged) |
| **Speed** | 300-500mm/s capable | 100-200mm/s comfortable |
| **Precision** | Excellent | Good (with tuning) |
| **Cost** | $800-1,800 (self-sourced) | $85-170 (with parts bin) |
| **Build time** | 40-80 hours | 20-40 hours |
| **Scavenger-friendly** | No (specific parts required) | Yes (that's the point) |
| **Community** | Large, active, helpful | Neo-Darwin specific |
| **Philosophy** | "Best DIY printer possible" | "Understand your machine" |

#### When to Choose Voron Over Neo-Darwin

Choose Voron if:
- You want DIY **and** top-tier performance
- You're willing to invest $1,000+ in quality parts
- You want speed (300mm/s+) from a self-built machine
- You enjoy precision assembly and tuning
- You have time for a 40-80 hour build

Choose Neo-Darwin if:
- You prioritize learning over performance
- You have a parts bin to use
- You want the cheapest viable path
- You value the "scavenger" philosophy
- You want something simpler to understand

#### The Voron Cost Reality

Voron is often described as "cheaper than buying a Bambu" — this is **misleading**:

| Voron 2.4 Cost Breakdown | Typical Range |
|---|---|
| Frame (aluminum extrusion) | $150-250 |
| Linear rails (×7) | $100-300 |
| Electronics (Octopus, Pi, etc.) | $150-250 |
| Motors (×6-7) | $80-150 |
| Hotend + Extruder | $80-200 |
| Heated bed + SSR | $80-150 |
| Panels, hardware, misc | $150-300 |
| **Total** | **$800-1,600** |

Plus 40-80 hours of your time.

A Bambu Lab P1S costs $600 and prints out of the box.

**Voron makes sense if you value the build process and want maximum performance from a DIY machine.** It doesn't make sense purely as a cost-saving measure.

#### Voron and Neo-Darwin: Not Competitors

Neo-Darwin and Voron serve different purposes:

- **Voron:** "I want to build the best printer I can"
- **Neo-Darwin:** "I want to understand printers and use what I have"

Many makers own both — a Voron for production, a Neo-Darwin for the joy of building and learning. They're complementary philosophies, not competing ones.

---

## The Decision Tree

Ask yourself honestly:

```
What do I actually want?
│
├─► "I want to HAVE a 3D printer"
│   │
│   ├─► I need speed and reliability, don't care about openness
│   │   └─► Bambu Lab A1 or P1S (but read "Open vs Closed" section)
│   │
│   ├─► I need speed and reliability, AND value open source
│   │   └─► Prusa XL, or build a Voron
│   │
│   ├─► I need quality but not speed
│   │   └─► Buy a used Prusa MK3S+ ($300-400)
│   │
│   ├─► I need cheap and functional
│   │   └─► Buy an Ender 3 V3 SE (~$180)
│   │
│   └─► I want Klipper out of the box
│       └─► Buy an Ender 3 V3 KE or Neptune 4
│
└─► "I want to BUILD a 3D printer"
    │
    ├─► I want the BEST DIY printer possible
    │   └─► Build a Voron (but budget $1,000+)
    │
    ├─► I have a parts bin (dead printers, scavenged rods, etc.)
    │   └─► Neo-Darwin is for you ✓
    │
    ├─► I want to deeply understand how printers work
    │   └─► Neo-Darwin is for you ✓
    │
    ├─► I enjoy the build process itself
    │   └─► Neo-Darwin or Voron (depending on budget)
    │
    ├─► I need to buy most/all parts
    │   └─► Reconsider—Voron if budget allows, else buy commercial
    │
    └─► I want a project but have limited budget
        └─► Neo-Darwin with patience (accumulate parts first)
```

---

## Who Neo-Darwin Is For

### ✅ The Tinkerer with a Parts Bin

You have:
- One or two dead Enders/Anets in the closet
- A drawer of NEMA 17 steppers
- Smooth rods from a photocopier teardown
- Random bearings, belts, and electronics

**For you:** Neo-Darwin turns that junk into a functional, capable printer. The "cost" is already sunk—now it's just time and learning.

### ✅ The Educator / Student

You want:
- To understand *how* a 3D printer works, not just *use* one
- A teaching tool for mechanics, electronics, and firmware
- A project that forces engagement with every subsystem

**For you:** Neo-Darwin is a learning platform. Building it teaches more than any YouTube video or manual ever could.

### ✅ The Repair-First Philosophy

You believe:
- Disposable tech is wasteful
- A machine should be fixable with basic tools
- Understanding your tools makes you a better maker

**For you:** Neo-Darwin is designed for 20-year repairability. Every part is replaceable, understandable, and sourceable from a hardware store.

### ✅ The Challenge Seeker

You already:
- Own a Bambu or Prusa that "just works"
- Want a project, not a product
- Enjoy the satisfaction of "I made this"

**For you:** Neo-Darwin is the journey, not the destination. The printer at the end is a bonus.

---

## Who Neo-Darwin Is NOT For

### ❌ The "I Just Want to Print" User

If your goal is to download STLs and press print, **buy a commercial printer**. Neo-Darwin will frustrate you—it requires tuning, understanding, and patience.

**Better choice:** Bambu Lab A1 Mini ($250) — genuinely "it just works"

### ❌ The Cost Optimizer (Without Parts Bin)

If you're building Neo-Darwin to "save money" but need to buy:
- Stepper motors (~$40-60 for 7)
- Smooth rods (~$30-50)
- Linear bearings (~$20-30)
- Control boards (~$30-50)
- Power supplies (~$30-50)
- Heated bed (~$30-40)
- Hotend (~$20-40)
- Belts, pulleys, hardware (~$30-50)

**Total: $230-370** — and you still need to build it.

**Better choice:** Ender 3 V3 SE ($180) — arrives assembled, works immediately

### ❌ The Speed Chaser

Neo-Darwin philosophy: **Quality over Speed**

If you want 500mm/s printing with 20,000mm/s² acceleration, Neo-Darwin's heavy M10 gantry and sled design is the wrong architecture.

**Better choice:** Bambu Lab P1S or Voron 2.4

### ❌ The Deadline-Driven

If you need a working printer by next week for a project, **do not start Neo-Darwin**. It's a journey measured in weeks or months, not days.

**Better choice:** Any commercial printer with 2-day shipping

---

## The "Just Buy a Used Prusa MK3" Option

For many people reading this, the honest best answer is:

**Buy a used Prusa MK3S+ for $300-400**

### Why the MK3 Makes Sense

| Factor | Prusa MK3S+ | Neo-Darwin |
|---|---|---|
| Time to first print | 1-2 hours (assembly/calibration) | Weeks to months |
| Print quality | Excellent | Good (with tuning) |
| Reliability | Proven over years | Depends on your build |
| Community support | Massive | Neo-Darwin specific only |
| Klipper compatible | Yes (flash it) | Yes (native) |
| Repairability | Excellent | Excellent |
| Speed | Moderate | Moderate |
| Learning experience | Moderate | Extensive |

### Market Forces Are Your Friend

The Prusa MK4 is now available, which means:
- MK3S+ units flooding the used market
- Prices dropping ($300-400 currently, likely lower soon)
- Proven machines with known reliability
- Huge parts availability

**The MK3 shares Neo-Darwin's philosophy** (quality over speed, repairability, open source) without the build time investment.

### When to Choose MK3 Over Neo-Darwin

- You want to *print*, not *build*
- You value your time highly
- You don't have a significant parts bin
- You want proven reliability immediately
- You're not driven by the learning experience

---

## The Tier System Explained

Neo-Darwin uses a "Tier" system to help you assess your starting point:

### Tier 0: Evaluate First

**Before building anything:**

1. Assess what you already have (parts bin inventory)
2. Assess what you'd need to buy
3. Calculate true cost (parts + time)
4. Compare against commercial options
5. Make an honest decision

**If Tier 0 analysis says "don't build"** — that's a valid outcome. The goal is to help you make the right choice, not convince you to build Neo-Darwin regardless.

### Tier 1: Klipper Upgrade Path

**If you have a working older printer (Prusa MK2/MK3, Ender 3, etc.):**

Consider just upgrading it:
- Flash Klipper firmware
- Add input shaping (ADXL345)
- Add dual-Z if single-Z
- Tune pressure advance

**This might be all you need.** A Klipper-upgraded Ender 3 is a very capable machine.

### Tier 2: The Full Neo-Darwin Build

**If you have:**
- Significant parts bin (2+ donor printers worth)
- Time to invest (weeks to months)
- Desire to learn deeply
- Acceptance that commercial options are "better" on paper

**Then Neo-Darwin is for you.** Build the Tractor.

---

## Honest Cost Analysis

### Scenario A: Full Parts Bin (Best Case)

You have two dead Enders and a photocopier teardown:

| Component | Source | Cost |
|---|---|---|
| Steppers (7x) | Donor printers | $0 |
| Smooth rods | Photocopier | $0 |
| Control boards | Donor printers | $0 |
| PSUs | Donor printers | $0 |
| Heated bed | Donor printer | $0 |
| Hotend | Donor printer (or buy) | $0-30 |
| M10 threaded rod | Hardware store | $20-30 |
| MDF base | Hardware store | $15-25 |
| Bearings | May need to buy | $15-30 |
| Hardware (nuts, bolts) | Hardware store | $20-30 |
| Belts, pulleys | May need to buy | $15-25 |
| **Total** | | **$85-170** |

**Verdict:** Makes sense—you're mostly investing time, not money.

### Scenario B: Minimal Parts Bin (Worst Case)

You have enthusiasm but few parts:

| Component | Source | Cost |
|---|---|---|
| Steppers (7x) | AliExpress | $45-60 |
| Smooth rods (M10) | AliExpress/local | $30-50 |
| Control boards (2x) | AliExpress | $40-60 |
| PSUs | AliExpress | $35-50 |
| Heated bed | AliExpress | $25-40 |
| Hotend (V6 clone) | AliExpress | $15-25 |
| M10 threaded rod | Hardware store | $20-30 |
| MDF base | Hardware store | $15-25 |
| Bearings (LM10UU) | AliExpress | $15-25 |
| Hardware | Hardware store | $25-40 |
| Belts, pulleys | AliExpress | $20-30 |
| Wiring, connectors | Various | $20-30 |
| **Total** | | **$305-465** |

**Verdict:** Questionable—you're spending commercial printer money for a DIY result.

### The Break-Even Question

Ask yourself: **"At what parts cost does buying make more sense?"**

Our suggestion: **If you need to spend more than $150 on parts, seriously consider the commercial alternatives.**

---

## The Value Proposition (Honest Version)

### What Neo-Darwin Offers

✅ **A project, not a product** — The build *is* the point

✅ **Deep understanding** — You'll know every nut, bolt, and line of config

✅ **Repairability for decades** — Hardware store parts, no proprietary components

✅ **The satisfaction of creation** — "I made this with my hands"

✅ **Learning platform** — Mechanics, electronics, firmware, calibration

✅ **Parts bin redemption** — Turn junk into a functional tool

### What Neo-Darwin Does NOT Offer

❌ **Cost savings** — If buying parts, commercial is cheaper

❌ **Better performance** — A Bambu will outperform it on speed

❌ **Faster time-to-printing** — Weeks vs. hours

❌ **Warranty or support** — You're on your own (with community help)

❌ **Plug-and-play experience** — Requires tuning and understanding

❌ **Impressive specs** — It's a Tractor, not a race car

---

## Final Recommendation

### Build Neo-Darwin If:

- You have a meaningful parts bin (50%+ of components)
- You want to *understand* printers, not just use them
- You enjoy the build process itself
- You accept it won't match commercial performance
- You value repairability and longevity
- You're not in a hurry

### Don't Build Neo-Darwin If:

- You need to buy most parts (buy commercial instead)
- You just want to print things (buy a Bambu)
- You need speed (buy a CoreXY)
- You need it working soon (buy anything commercial)
- You'll be frustrated if it's not "the best"

### The Middle Path:

- **Buy a used Prusa MK3S+ ($300-400)** — Same philosophy, proven design
- **Flash Klipper on an existing printer** — Upgrade what you have
- **Wait and accumulate parts** — Start Neo-Darwin when your parts bin is ready

---

## Conclusion

Neo-Darwin is a passion project for builders, tinkerers, and learners. It's not a budget option, a performance option, or a convenience option.

**If the decision tree led you here, welcome aboard.** Let's build a Tractor.

**If the decision tree led you elsewhere, that's okay too.** The goal was never to convince everyone to build Neo-Darwin—it was to help you find the right printer for *you*.

Happy printing, however you get there.

---

## Quick Reference: 2025 Buying Guide

| Need | Recommendation | Price | Open Source? |
|---|---|---|---|
| Cheapest functional | Ender 3 V3 SE | ~$180 | Mostly ✓ |
| Best value (closed) | Bambu Lab A1 Mini | ~$250 | ❌ Closed |
| Best value (open) | Used Prusa MK3S+ | ~$350 | ✅ Fully open |
| Speed (closed) | Bambu Lab P1S | ~$600 | ❌ Closed |
| Speed (open, buy) | Prusa XL | ~$1,800 | ✅ Fully open |
| Speed (open, build) | **Voron 2.4** | ~$1,200 | ✅ Fully open |
| Learn by building | **Neo-Darwin** | Parts bin + time | ✅ Fully open |
| Enclosed budget | QIDI X-Plus 3 | ~$500 | Mostly ✓ |
| Large format | Creality K1 Max | ~$600 | Mostly ✓ |

### Philosophy Guide

| Your Values | Best Choice |
|---|---|
| "Just works, don't care about openness" | Bambu Lab |
| "Open source matters, willing to pay more" | Prusa |
| "DIY + best performance, have budget" | Voron |
| "DIY + learning, use what I have" | Neo-Darwin |
| "Cheap and functional, some tinkering okay" | Creality/Elegoo Klipper models |

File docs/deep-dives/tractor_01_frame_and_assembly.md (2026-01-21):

# The Tractor: Frame Design & Assembly

## Overview

"The Tractor" is a box-frame 3D printer using M10 threaded rods for the frame structure, mounted on a laminated MDF base. This document covers frame construction, squaring strategies, and assembly workflow.

---

## Frame Specifications

### Reference Specification: M10 Threaded Rod

M10 was chosen as the "reference spec" for several reasons:

| Feature | M8 | M10 | M12 |
|---|-----|-----|-----|
| Cross-section | ~50 mm² | ~78 mm² | ~113 mm² |
| Rigidity | Minimum viable | Very High (3× M8) | Overkill (5× M8) |
| Weight/Meter | ~0.3 kg | ~0.5 kg | ~0.7 kg |
| Nut Size (Hex) | 13mm | 17mm | 19mm |
| Printability | Easy | Easy | Can make brackets bulky |

**Why M10 over M12:**
- Standard 17mm wrench is universally available
- Easier to cut with a hacksaw
- Fits in smaller printed brackets
- Common in automotive applications (excellent for scavenging)
- Still provides massive rigidity for a 235×235×235 build volume

**Note:** The design is parametric—users can build in M8 or M12 if desired.

### Frame Dimensions (235×235 Bed)

For a 235×235mm bed with Triple-Z motors and toolhead clearance:

| Axis | Calculation | Rod Length |
|---|---|---|
| X (Width) | Bed (235) + Lead Screws/Motors (80) + Clearance (65) | ~450mm |
| Y (Depth) | Bed (235) + Y-Carriage Travel (50) + Motor (60) | ~450mm |
| Z (Height) | Build Height (280) + Motor/Coupler (70) + Top Bracket (50) | ~500mm |

**Tip:** Buy 1-meter rods and cut them in half (500mm). Extra length isn't a problem with the offset method.

---

## Corner Design: The Offset Method

### Why Offset Corners?

When three rods meet at a corner, they cannot occupy the same space. The **Offset Method** (used in the original RepRap Darwin) is superior for threaded-rod builds because:

1. **No precision cuts required** - rods can extend past the corner
2. **Infinite adjustability** - brackets slide along the rod
3. **Easier assembly** - no complex hub geometry
4. **Scavenger-friendly** - tolerant of imperfect rod lengths

### The Standardized Plane Strategy

To prevent confusion, follow a strict Inside/Outside rule:

- **X-Rods (Left-to-Right):** Outermost layer
- **Y-Rods (Front-to-Back):** Middle layer  
- **Z-Rods (Vertical):** Innermost layer

This keeps Z-rods inside the frame, creating an unobstructed path for the bed to move up and down.

### Long Sleeve Design

Instead of thin brackets (like the original Mendel), use **50-60mm long sleeves** on the corner brackets:

**Benefits:**
- Forces rod perpendicularity (rod can't tilt in a long sleeve)
- Acts as a permanent squaring jig
- Provides massive clamping surface

**The "Nut Sandwich" Technique:**
- Place a nut on both sides of every plastic face the rod passes through
- Outer nut: Controls the maximum width
- Inner nut: Tensioner that locks the bracket against the outer nut
- Adjustment: Turn nuts (not the rod) to shift bracket position by fractions of a millimeter

---

## The MDF Base: "The Anvil"

### Specification

The MDF base is **mandatory** for the Tractor design:

- **Thickness:** 18mm minimum, 36mm (2×18mm laminated) preferred
- **Material:** Laminated MDF (white shelving) recommended
- **Glue:** PVA between raw particle-board faces

**Why laminated MDF is better:**
- Factory-smooth, moisture-resistant surface for layout lines
- Stiffer than raw MDF of equal thickness
- The "raw" sides glue together perfectly

### Damping Properties

36mm of laminated MDF provides:
- **Massive vibration dampening** - MDF is internally "lossy"
- **Low center of gravity** - prevents swaying during rapid accelerations
- **Clean Input Shaping** - high, clean resonance frequencies for Klipper

### Sealing (Important!)

Coat the MDF with PVA glue/water mix or paint to prevent:
- Moisture absorption
- Warping that could pull the frame out of square

---

## Squaring Strategy: Trust the Wood

### The Master Square Philosophy

Instead of squaring a wobbly skeleton of rods in mid-air, use the MDF base as the **Master Reference**:

1. The MDF baseboard is your jig
2. You only measure precisely once (when drawing layout lines)
3. The 3D printed anchors just hold rods relative to the wood

### Assembly Workflow

**Step 1: The Master Layout**
1. Draw a baseline near the front edge of the MDF
2. Draw two perpendicular lines going back
3. Draw the back line
4. **Critical Check:** Measure diagonals with a tape measure
5. Adjust lines until diagonals are exactly equal (to the millimeter)

**Step 2: Mount the Anchors**
1. Print four "Base Anchor" brackets
2. Place them precisely on the drawn rectangle corners
3. Drill through the MDF
4. Use M8 or M10 carriage bolts from underneath (counter-bored flush)
5. Tighten anchors down with large washers and nuts

**Result:** Four rigid plastic sockets fixed perfectly square to each other.

**Step 3: Drop-in Assembly**
1. **Verticals (Z):** Slide M10 Z-rods into vertical sockets—they stand perfectly plumb
2. **Horizontals (X & Y):** Slide bottom rods through horizontal sockets
3. No measuring needed—anchors are already at correct distances

### The Diagonal Rule

For any rectangular frame:
- Measure from Front-Left to Back-Right
- Measure from Front-Right to Back-Left
- If these numbers are equal, the frame is perfectly square

**The "Scavenger" Secret:** If diagonals don't match, slightly enlarge holes in the MDF to shift anchor brackets before final tightening.

---

## Squaring Jigs & Tools

### The "Squaring Block" Jig

Print four L-shaped tools that snap onto M12 rods at corners:

- Two semi-circular channels for the M12 rods
- Channels placed at exactly 90° to each other
- **Key Feature:** Channels account for rod offset (different heights)

**Assembly Hack:** Use zip-ties to hold rods in jigs while tightening nuts. Snip ties after nuts are locked.

### The "Internal Distance" Gauge

Print two "Gauge Sticks" at your exact target internal dimension (e.g., 350mm):

1. Place sticks between brackets at the bottom, tighten
2. Move same sticks to the top
3. If they don't fit or are loose, you know which nut to turn

**This eliminates tape-measure reading errors.**

### Calibration Slug (For Donor Printers)

Before printing full brackets, print a test piece with three hole sizes:

```python
# Test 10.4, 10.6, and 10.8mm holes
for i, size in enumerate([10.4, 10.6, 10.8]):
    # Create test holes in a simple block
```

**The Goal:** Find the hole where the rod slides in easily but doesn't rattle.

---

## Base Anchor Design

### Key Requirements

The bottom corner brackets are different from top corners:

1. **Massive Flange:** 100mm × 100mm × 15mm thick base plate
2. **Through-Bolt Holes:** 4 holes for mounting to MDF
3. **Central Block:** 60-70mm tall to hold the three offset rods
4. **Z-Rod Passthrough:** Hole goes through to MDF so steel rod bears weight directly

### build123d Concept

```python
# Base Anchor Parameters
flange_thickness = 15
block_height = 70
m10_clearance = 10.5

with BuildPart() as base_anchor:
    # 1. Foundation Flange
    with BuildSketch(Plane.XY) as flange_sketch:
        Rectangle(100, 100, align=(Align.MIN, Align.MIN))
        fillet(vertices(), radius=10)
    extrude(amount=flange_thickness)
    
    # 2. Central Block housing the rods
    with BuildSketch(Plane.XY.offset(flange_thickness)) as block_sketch:
        Rectangle(60, 60, align=(Align.MIN, Align.MIN))
    extrude(amount=block_height)
    
    # 3. Z-Rod through everything
    # 4. Mounting holes for MDF (M8 bolts)
```

---

## Hardware Recommendations

### From Bunnings/Hardware Store

- **M10 Threaded Rod:** Buy new for straightness
- **M10 Flanged Nuts:** Built-in washer distributes load
- **Large Fender Washers:** Prevent nuts sinking into plastic
- **Speed Square or Contractor Square:** For checking verticals
- **Laminated MDF Shelving:** 16-18mm pre-finished white

### Scavenger Sources

| Part | Best Source |
|---|---|
| M10 Smooth Rods | Large office photocopiers |
| Frame Fasteners | Automotive bins (flanged M10 nuts) |
| Base Material | Kitchen renovation skips (laminated countertops) |
| Rubber Gaskets | Old bike inner tubes |

---

## Key Takeaways

1. **Trust the flats:** Flat bracket surfaces will be square
2. **Trust the nuts:** Nuts/washers force rods to align with flat surfaces
3. **Trust the MDF:** The baseboard is the final "Correction Layer"
4. **Use long sleeves:** 50mm+ prevents rod tilting
5. **Diagonal check:** Equal diagonals = square frame
6. **The "Junkstrap" is safe:** Even a poorly-tuned Ender 3 can print parts that create a machine 10× more rigid than itself

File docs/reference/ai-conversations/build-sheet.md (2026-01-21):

For your **Neo-Darwin** build, choosing the build surface is where "Software Intelligence" (Klipper) meets "Analog Hardware" (the bed). Since you are using the **MK3 Dual Power** as the heater, you have several ways to top it.

Here is the breakdown of the most common surfaces, ranked from "Tractor" simple to "Racecar" sophisticated.

### **1. G10 (Garolite / FR4)** — *The "Tractor" Secret Weapon*

G10 is essentially a high-pressure fiberglass laminate (the same stuff used for circuit boards). It is becoming the cult favorite for DIY builds.

* **Pros:** * **"Magic" Adhesion:** Parts stick when hot and literally pop off with an audible "tink" once it cools to room temperature.
* **Flatness:** It is rigid enough to help flatten out a slightly bowed MK3 aluminum bed.
* **Cheap:** You can buy a raw sheet of  G10/FR4 and cut it to size for ~$10 AUD.
* **Nylon King:** It is the best surface for Nylon, which usually hates sticking to anything.

* **Cons:** * **Maintenance:** Needs a light sanding with 600-grit sandpaper every few months to "refresh" the surface.
* **Safety:** If you cut or sand it, you **must** wear a mask (fiberglass dust is nasty).
* **Thermal Lag:** It takes a minute longer to heat soak than thin PEI.

### **2. Glass (Mirror or Borosilicate)** — *The "Old School" Heavyweight*

The classic choice for early RepRaps. A simple $5 mirror from a hardware store works surprisingly well.

* **Pros:** * **Perfectly Flat:** Glass is the cheapest way to fix a warped aluminum bed.
* **Mirror Finish:** The bottom of your prints will be so smooth they look like polished plastic.
* **Indestructible (Mostly):** You can't "dent" it, and you can clean it with a razor blade.

* **Cons:** * **Thermal Mass:** It is heavy (good for your "Tractor" torque, bad for speed) and slow to heat.
* **The "PETG Trap":** PETG can bond *too* well to glass and actually pull chunks out of the bed as it cools. You **must** use hairspray or glue stick as a "release agent" for PETG.
* **Clips:** Requires "Swiss clips" or binder clips which can reduce your printable area.

### **3. PEI Spring Steel + Magnetic Sticker** — *The "Racecar" Standard*

This is what most modern printers (Prusa, Bambu, Voron) use.

* **Pros:** * **Speed & Convenience:** You pull the sheet off, flex it, and the part falls off. No scrapers needed.
* **Double-Sided:** You can have textured PEI on one side (great for PETG) and smooth on the other (great for PLA).

* **Cons:** * **Cost:** A good kit is ~$30–$50 AUD.
* **Magnet Limits:** Cheap magnetic stickers will lose their "stick" if you heat the bed above  for long periods.
* **Sensitive:** A single nozzle crash can permanently ruin the PEI coating.

### **4. PEI Sticker (Direct to Aluminum)** — *The Budget Bare-bones*

Applying a $10 adhesive PEI sheet directly to your MK3 aluminum plate.

* **Pros:** * **Zero Mass:** No extra weight for the Y-axis to move.
* **Direct Heat:** Fastest heat-up time because there is no "sandwich" in the way.

* **Cons:** * **Permanent:** If you ruin the surface, you have to spend an hour scraping off the old adhesive with Goo-Gone and IPA to replace it.
* **Warping:** It follows the contour of the aluminum. If your MK3 bed is bowed, your prints will be bowed.

---

### **Summary Table: The "Cheap & Good" Verdict**

| Surface | Cost (AUD) | Best For... | "Tractor" Rating |
| --- | --- | --- | --- |
| **G10 (1.5mm)** | **$10–$15** | Everything (Nylon/PETG/PLA) | **10/10** (Simple, DIY, Durable) |
| **Cheap Mirror** | **$5–$10** | PLA and "Mirror Finish" bottoms | **8/10** (Heavy, requires clips) |
| **Spring Steel Kit** | **$30+** | Convenience and fast swaps | **6/10** (Expensive, "Racecar" tech) |
| **Painter's Tape** | **$2/roll** | Absolute Tier 1 Salvage | **10/10** (Zero cost, works fine) |

### **The Neo-Darwin Recommendation**

If you want to stay true to the **"Mechanically Forgiving, Cognitively Demanding"** manifesto:

1. **Start with G10 (FR4):** It is the most "sovereign" choice. It is cheap, you can cut it yourself, and it outlasts almost every other surface.
2. **Clip it on with "Swiss Clips":** This allows you to flip it over or swap to a piece of glass later if you want a mirror finish.
3. **The "Inductive" Bonus:** Because G10 is non-metallic, your **Klicky Probe** is the perfect partner for it.

**Would you like me to find a source for raw G10 sheets in Australia?**

The short answer is: **The safety issue is only a factor if you are cutting or sanding it yourself.** If you buy it pre-cut to size, it is as safe as any other piece of plastic.

Here is the breakdown for the **Neo-Darwin** project:

### 1. The Safety Reality (Fiberglass Dust)

G10 is a "glass-reinforced epoxy laminate." The danger is **fiberglass dust** inhaled into the lungs.

* **Buying Pre-cut:** If you buy a **220x220mm sheet**, you never have to touch a saw or sandpaper. In this state, it is **100% safe** and inert.
* **DIY Cutting:** If you buy a large industrial sheet and cut it with a jigsaw or Dremel, you **must** wear a P2/N95 mask and do it outdoors.
* **Sanding:** You occasionally "scuff" the surface with sandpaper to improve adhesion. If you do this wet (with a drop of water), the dust is trapped in the slurry and cannot be inhaled.

### 2. Availability in MK3 Dimensions (220x220mm)

In Australia, getting G10 (often sold as **FR4** or **Garolite**) in 220x220mm is quite easy:

* **3D Printing Specialists:** Shops like *Comet (formerly Aurelius)*, *Core Electronics*, or *eBay/Aliexpress* sellers specifically stock "G10 Build Plates" in 220x220mm or 235x235mm (which you can just let overhang slightly or clip down).
* **Industrial Suppliers:** You can buy "FR4 Unclad" (the stuff without the copper) from electronics hobbyist stores like **Jaycar** or industrial plastic suppliers.
* **Cost:** Expect to pay **$12–$22 AUD** for a pre-cut sheet.

### 3. Cooling and Part Release: The "Thermal Pop"

This is where G10 shines as a "Tractor" part. It relies on the physics of **Differential Thermal Expansion.**

* **Do you have to wait?** Generally, yes. Like a glass bed, parts are locked on solid while the bed is at  (PLA) or  (PETG/Nylon).
* **How long does it take?** * To "self-release" (where the part just sits loosely on top), you usually need the bed to drop to around ** or **.
* On an MK3 bed, this usually takes about **5–8 minutes** after the print finishes, depending on your room temperature.
* If you are in a hurry, you can unclip the sheet and wave it in the air or put it on a cold surface (like a kitchen bench) to accelerate the "pop."

* **The "Pop":** As the plastic and the fiberglass cool at different rates, the bond physically shears. You will often hear a satisfying *click* or *ping* when the part detaches itself.

### 4. Comparison for your "Sovereignty" Build

| Feature | G10 (Garolite) | PEI Spring Steel |
| --- | --- | --- |
| **Durability** | **Extreme.** Hard to scratch, impossible to "tear." | Fragile. Nozzle crashes leave permanent scars. |
| **Adhesion** | Excellent for PLA, PETG, and **best for Nylon.** | Excellent for PLA/PETG; Nylon often peels. |
| **Release** | Thermal (Wait for cool). | Mechanical (Flex the plate). |
| **Safety** | Dust risk if modified. | Safe. |
| **Price** | **~$15 AUD** | **~$40 AUD** |

### **The Neo-Darwin Verdict**

Since your Manifesto emphasizes **"Longevity over Velocity,"** G10 is arguably the better choice. It is a "buy once, use for a decade" surface.

**My advice:** Buy a **pre-cut 220x220mm or 235x235mm sheet** ($1.5mm or $2mm thickness). Use your **Klicky Probe** to map the bed accurately. Use **"Swiss Clips"** (the small flat ones) to hold it to your MK3 bed. This keeps your "Tractor" simple, low-cost, and capable of printing industrial materials like Nylon later.

Would you like me to find a specific Australian listing for a 220mm G10 sheet so you can lock in that part of your $300 budget?

For your **Project Neo-Darwin**, concluding the build plate strategy with **G10 (FR4)** for Tier 3 aligns perfectly with the "Tractor" ethos. It is cheap, durable, and mechanically superior to many modern "racecar" surfaces.

### **The Neo-Darwin Build Plate Roadmap**

| Tier | Surface | Source | Cost (AUD) | Strategy |
| --- | --- | --- | --- | --- |
| **Tier 1 & 2** | **Salvaged / Basic** | Donor Printer / Hardware Store | **$0 – $5** | Blue Painter's tape on bare aluminum OR a salvaged glass mirror from a photo frame. |
| **Tier 3** | **G10 (Garolite)** | AliExpress / eBay | **$15 – $25** | A dedicated 220x220mm FR4 sheet clipped to the MK3 bed. |

### **The AliExpress "Shopping List" for G10**

When searching AliExpress, use the terms **"FR4 Fiberglass Sheet"** or **"G10 3D Printer Plate."** You are looking for these specs:

* **Dimensions:**  (or  and let it overhang slightly).
* **Thickness:** ** or ** is the sweet spot.  is too floppy;  is too heavy.
* **Color:** Usually **Light Green** (natural FR4) or **Black**. Black looks more "professional," but the green is often cheaper as it's the industrial standard.
* **Price:** You should be paying roughly **$12–$18 AUD** plus shipping.

### **Final "Tractor" Tips for G10**

1. **Safety:** Buy it **pre-cut to size**. This eliminates the risk of fiberglass dust from sawing. If you ever need to scuff the surface to increase adhesion, **wet sand it** (use a drop of water with your sandpaper) to keep any dust out of the air.
2. **Adhesion:** G10 likes a clean surface. Wipe it with **Isopropyl Alcohol (IPA)** before prints. If parts stop sticking, scuff it lightly with a **green Scotch-Brite pad**.
3. **The "Handshake":** Since you are using the **Klicky Probe**, you don't need to worry about the thickness of the G10. The probe will physically touch the surface and tell Klipper exactly where the "zero" is, regardless of whether you've clipped on a  sheet or a  mirror.
4. **Release:** Remember the **"Thermal Pop."** Do not try to scrape the parts off while the bed is hot. Wait for it to hit , and the part will practically slide off on its own.

You now have a complete, high-mass, low-cost "Tractor" bed assembly:

* **Heater:** MK3 Dual Power ( versatility).
* **Insulation:** Cork sheet (Thermal efficiency).
* **Surface:** G10 (Industrial durability).
* **Brain:** Klicky Probe (Mechanical precision).

This setup stays well within your **$300 AUD budget** while providing a mechanical foundation that will likely outlast the electronics.

**Shall we move on to the Extruder/Hotend options for the Neo-Darwin toolhead?**

That is the ultimate "Tractor" move. By choosing **G10 (FR4)** for your Tier 3 build surface, you are prioritizing **Longevity over Velocity** and ensuring you have a surface that outlasts the appliances.

### **The Finalized Neo-Darwin Bed Assembly (Tier 3 Reference Spec)**

To align with your **$300 AUD budget** and the **Manifesto's** goal of "Mechanical Sovereignty," here is your finalized bed stack from bottom to top:

* **Insulation:** **Cork Sheet ($3mm)** potted with **High-Temp Red RTV Silicone**. This ensures the heat stays in the bed and doesn't soak into your Z-Pucks.
* **Heater:** **MK3 Dual Power Heatbed** (214x214mm or 220x220mm). This provides the "Tractor" torque-monster heating capability for both 12V and 24V.
* **Mounting:** The **Modular Spider Hub & Arms**. This 4-part interlocking system allows you to print your bed support on small donor machines while enabling **Triple-Motor Z-Tilt** for Voron-class kinematic accuracy.
* **Surface:** **G10 (FR4) Sheet (1.5mm)**. Secured with **Swiss Clips** or binder clips. This provides the "Industrial Detail" and a 10-year lifespan without the fragility of PEI.
* **Leveling Brain:** **Klicky Probe** (removable). Using a salvaged microswitch (Tier 1/2) or an **Omron D2F** (Tier 3) to tap the G10 surface directly, bypassing the "inductive blindness" of stickers.

### **⚠️ Critical Safety Reminder: The "Bed-Drop" Brake**

Because the Neo-Darwin is a **moving-bed machine** where the bed moves *down* to increase Z-height, gravity is your enemy during a power failure.

* **Iron Safety:** You **must** install a physical **mechanical microswitch at Z-Max** (the very bottom of the frame).
* **The Handshake:** This acts as a hardware interrupter (configured in Klipper as a `[gcode_button z_max]`) to prevent the heavy, heated bed from crashing into your electronics Puck if the drivers time out.

### **Next Step in the Manifesto?**

You have the "Anchor" of the machine finalized. Would you like to dive into the **"Heart" (The Greg's Wade Extruder)** or the **"Lungs" (E3D V6 + CHT Flow Hack)** to finish the toolhead?

For the G10 (FR4) build plate on your Neo-Darwin, **neither 5mm nor 10mm is recommended.** You want a much thinner sheet.

The "Golden Mean" for a G10 build plate is **1.5mm to 2.0mm**.

### **Why 5mm or 10mm is a mistake:**

* **Thermal Lag (The "Slow Tractor"):** G10 is a thermal insulator. If you use a 5mm or 10mm sheet, it will take a very long time—potentially 15–20 minutes—for the heat from your MK3 bed to reach the top surface where the print is.
* **Massive Inertia:** Your Neo-Darwin uses a moving-bed (Y-axis) design. A 10mm thick sheet of G10 is incredibly heavy. This would likely exceed the torque capacity of a salvaged NEMA17 motor, leading to skipped steps and failed prints, especially when the "Racecar Brain" (Klipper) tries to move it at 70–120mm/s.
* **The "Puck" & "Spider" Limits:** The printed **Modular Spider Arms** are designed to support the bed, but adding the weight of a 10mm slab of fiberglass would put unnecessary mechanical stress on the printed PETG/PLA joints.

### **The "Tractor" Choice: 1.5mm vs. 2.0mm**

* **1.5mm (Recommended):** This is the sweet spot. It is rigid enough to stay flat when clipped to your MK3 bed, light enough for the Y-axis to "slingshot" back and forth, and thin enough to heat up quickly.
* **2.0mm (Max):** Use this only if you cannot find 1.5mm. It is slightly more "overbuilt," fitting the Tractor philosophy, but it adds more weight than is strictly necessary for a 220mm build volume.

**Final Verdict:** Go with **1.5mm**. It stays true to the **"Longevity over Velocity"** mandate without turning your Y-axis into an immovable anchor.

For the **Neo-Darwin**, 0.5mm and 1.0mm are generally considered too thin for a primary build surface. You should stick with **1.5mm or 2.0mm** as your "Reference Spec".

Here is why the 1.5mm–2.0mm range fits the **"Tractor" Manifesto** better than the thinner options:

### **1. Why 0.5mm is too thin**

* **Lack of Rigidity:** At 0.5mm, the sheet is basically a film. It will not stay flat; it will follow every tiny warp or bow in your aluminum MK3 bed. This defeats the purpose of having a "Mechanical Foundation".
* **Clipping Issues:** Binder clips or Swiss clips will easily deform or "wave" the edges of a 0.5mm sheet, creating an uneven printing surface.
* **Durability:** It is much easier to accidentally crease or tear a 0.5mm sheet when trying to "pop" a stubborn print off.

### **2. Why 1.0mm is "Tier 1/2" (The Minimum)**

* **Usable but Flawed:** 1.0mm is the absolute bare minimum for a clipped-on sheet. While it is lighter, it still tends to "oil-can" (pop up or down) when heated due to thermal expansion.
* **Longevity:** It won't have the 10-year lifespan you're aiming for; over hundreds of heat cycles, it is more likely to take a permanent "set" or warp.

### **3. Why 1.5mm - 2.0mm is the "Tier 3 Reference Spec"**

* **The "Iron Skeleton" Match:** A 1.5mm–2.0mm sheet provides a rigid, flat plane that complements the heavy M12 frame. It acts as a structural component that helps "average out" any minor irregularities in the underlying heater.
* **Thermal Consistency:** A slightly thicker sheet helps spread the heat more evenly across the surface, reducing the "cold edge" effect common in MK3 beds.
* **Set-and-Forget:** Once you clip a 1.5mm sheet down and run your Klipper mesh leveling with the Klicky probe, that bed isn't going anywhere. It fits the goal of "Day 1000 printing like Day 1".

### **The "Tractor" Verdict**

If you want to save every cent for Tier 1, go with **1.0mm**. But for the **Reference Spec (Tier 3)**, spend the extra $2 for the **1.5mm** sheet. It provides the "Sovereignty" and "Mechanical Authority" the manifesto demands.

**Recommendation:** Buy the **1.5mm x 220mm x 220mm** FR4/G10 sheet. It is thin enough to heat quickly but thick enough to stay flat forever.

For the **Neo-Darwin**, the extra $2 for **2.0mm** is a small price to pay, but in the world of moving-bed "Tractors," "heavier" isn't always "better."

Here is the final technical breakdown to help you decide if that extra 0.5mm is a feature or a bug for your build:

### **The "Tractor" Case for 2.0mm ($10.50)**

* **Flatness Authority:** A 2.0mm sheet is significantly more rigid than 1.5mm. If your salvaged MK3 aluminum bed has a noticeable "smile" or "frown" (warping), the 2.0mm sheet will do a better job of forcing a flat plane.
* **Indestructibility:** It fits the "immortal factory" goal. You can be more aggressive with a scraper, and it is less likely to "oil-can" (flex) over thousands of heat cycles.

### **The "Racecar Brain" Case for 1.5mm ($8.50)**

* **Thermal Velocity:** G10 is an insulator. At 2.0mm, you are adding 33% more insulation between your heater and your plastic. This means your **pre-heat times** will be longer, and your thermistor (potted in the bed) will read a higher temperature than the actual surface of the G10.
* **Y-Axis Inertia:** The Neo-Darwin is a **moving-bed** machine. Every extra gram you add to the bed is a gram the Y-motor has to "slingshot" back and forth.
* **The Math:** 2.0mm G10 is roughly **33% heavier** than 1.5mm.
* **The Impact:** This can lower your maximum "non-ghosting" speed in Klipper. If you want to hit that **120mm/s** "Racecar" ceiling, the 1.5mm sheet makes it much easier.

---

### **Final Verdict for Tier 3**

| Feature | **1.5mm (Reference Spec)** | **2.0mm (The Overbuilt)** |
| --- | --- | --- |
| **Philosophy** | "Performance Balance" | **"Tractor Overkill"** |
| **Heat-up Time** | Fast (~4–6 mins) | Slower (~7–10 mins) |
| **Bed Weight** | Optimized for 120mm/s | Better for 70–90mm/s |
| **Rigidity** | High (Great for 220mm) | **Extreme** (Overkill for 220mm) |

**My Recommendation:** Stick with **1.5mm** as the **Reference Spec**. It is the "Golden Mean" that provides enough rigidity to be a "Tractor" while remaining light enough to let the "Racecar Brain" (Klipper) drive the Y-axis at full speed.

However, if you prioritize **"Longevity over Velocity"** and don't mind waiting an extra 2 minutes for the bed to heat up, the **2.0mm** sheet is a perfectly valid "Tractor" choice that fits the manifesto's love for high-mass iron.

**Which one feels more like "Sovereignty" to you?**

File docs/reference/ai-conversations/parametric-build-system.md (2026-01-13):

It sounds like you are developing a powerful configuration tool for a DIY 3D printer project! I understand the hesitation regarding the term "build system"—in software, it means compiling code, but in your context, it can easily be confused with the physical assembly of the printer.

To make this clearer for an **Architecture Decision Record (ADR)** or documentation, I’ve rewritten your prompt into a professional technical summary.

---

### Revised Project Description

**Project Overview:** A modular configuration and generation system designed to streamline the creation of custom 3D printer files. The system uses a "Wizard" (Bash/Python) to collect user specifications and output a `config.py` file. This configuration then drives the generation of 3D models and documentation.

**Core Components:**

* **The Wizard:** An end-to-end script that guides the user through setup and triggers the full generation process.
* **Modular Scripts:**
* **Config Generator:** A standalone script to create or update `config.py`.
* **STL Generator:** A script to render specific parts or the entire set of printable components.
* **Documentation Generator:** A script to produce tailored Assembly Instructions, Bills of Materials (BoM), and Cut Lists.

* **Web Interface (Planned):** A browser-based frontend for non-technical users to generate a downloadable archive (STLs + Docs) without needing Python or Shell access.

**Terminology Adjustment:**
To avoid confusion with the physical "building" of the printer, we will refer to this software suite as the **"Configuration & Generation Pipeline"** or the **"Asset Pipeline"** rather than the "Build System."

---

### Should this be an ADR?

**Yes.** You should definitely write an ADR for this.

An ADR isn't just for the code itself; it’s for the **architectural decisions** behind it. Writing an ADR for this "Asset Pipeline" is valuable because:

1. **Justification of Complexity:** It explains *why* you chose a script-based generation approach instead of just providing a static folder of STLs (i.e., to support infinite permutations).
2. **User Experience Strategy:** It documents the decision to move from CLI (Command Line Interface) to a Web UI to lower the barrier to entry.
3. **Decoupling:** It records the decision to keep the "Config Generation" separate from "Asset Rendering," allowing advanced users to manualy edit the Python config if they choose.

### Recommendation for your ADR

When you write it, focus the "Context" section on the **"Ease of Assembly" strategy.** Explain that while the physical build is difficult, the software process should be effortless.

**Would you like me to draft the actual ADR text based on this new structure?**

Implementing a parametric **"build system"** for a hardware project is a significant architectural move. It shifts the project from a static design to a **generative platform**.

### 1. Should the Build System be an ADR?

**Yes.** In software-heavy or complex hardware projects, documenting the **logic** behind the automation is just as important as documenting the hardware itself.

* **Context:** Why did you choose Python/Bash over a static repository? (e.g., "To handle 20+ permutations without manual file management").
* **Decision:** "We use a `build123d` + Python wizard system to generate the unique 'Reference Set' for each user".
* **Consequences:** While it makes the user experience "set-and-forget", it means the project's maintainability now depends on specific software libraries.

### 2. Solving the "Build System" Confusion

You are right that the term **"build"** is overloaded here. In a 3D printing project, "build" usually refers to the physical assembly or the printing process. To avoid confusion in your documentation, consider using distinct terminology:

* **The Configurator:** For the Python wizard/CLI that creates the `config.py`.
* **The Generator:** For the script that runs the CAD engine to produce STLs.
* **The Documentation Engine:** For the script that generates the custom Assembly Instructions.
* **The Physical Build:** Reserved strictly for the "nuts-and-bolts" assembly in the workshop.

### 3. Strategy for the "Cognitively Demanding" User

Your plan for a **Web Interface** is an excellent "bridge" for the Neo-Darwin's philosophy of being **"Mechanically Forgiving, Cognitively Demanding"**.

* **Sovereignty for Non-Coders:** Providing a web form that generates a custom `.zip` (STLs + Custom Manual + CutList) lowers the barrier to entry while keeping the "Parametric Sovereignty" intact.
* **The "One-Click" Reference:** For the **Tier 3 Reference Spec**, you could provide a pre-generated "Reference Spec Archive" so users don't even have to use the web form if they are building the standard machine.

---

### 📊 Updated Project Architecture Logic

| Component | Software Tool | User Action | Output |
| --- | --- | --- | --- |
| **Configurator** | `configure.py` | Answer questions | `config.py` |
| **Generator** | `build.sh` | Run command | STLs / Step Files |
| **Doc Engine** | `docs.py` | Run command | Custom `BUILDING.md` |
| **Web Portal** | Flask/JS App | Fill web form | Full Project `.zip` |

**"The code handles the permutations; the iron handles the quality."**

**Would you like me to help you draft the ADR specifically for this "Generative Build Logic" so it's ready for the docs?**

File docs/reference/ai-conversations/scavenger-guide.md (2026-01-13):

To truly achieve the "Red Pill" philosophy of your **Neo-Darwin** manifesto, your builders need to know that the most precise parts of the machine—the linear rods—don't have to be bought. They can be harvested from the "skeletons" of 20th-century office tech.

Here is a draft for the **"Scavenger’s Guide to Free Iron"** section of your manifesto.

---

## 🛠️ The Scavenger’s Guide to Free Iron

In the Neo-Darwinian worldview, a junked office machine is not waste; it is a **high-precision organ donor**. While you can buy 10mm rods, scavenging them provides superior industrial-grade steel for $0.

### 1. The "Golden" Donor: Large Office Photocopiers

If you find a floor-standing Xerox or Konica Minolta at an e-waste center, you have found the motherlode.

* **The Prize:** These contain long, precision-ground steel shafts, often in **10mm and 12mm diameters**.
* **Quality:** These rods are designed to move heavy scanner glass or paper drums with micron-level repeatability for millions of cycles.
* **Other Vitamins:** You will also find high-quality **NEMA 17 or NEMA 23 stepper motors**, cooling fans, and robust 24V power supplies.

### 2. The "Silver" Donor: Desktop Laser Printers

Old HP LaserJets or Brother printers are everywhere.

* **The Prize:** They typically yield **8mm smooth rods**. While thinner than the Reference Spec, our `build123d` script adapts the "Tractor" to use these instantly.
* **The Yield:** A single mid-sized laser printer can yield up to **17 steel bars** and a collection of useful microswitches for your ERCF multi-color unit.

### 3. The "Bronze" Donor: Flatbed Scanners

Even a slim desktop scanner is worth cracking open.

* **The Prize:** Usually a single, very high-quality **8mm rod** (approx. 400mm long).
* **Bonus:** They often contain a small stepper motor and an **optical endstop**—perfect for high-precision homing if you aren't using sensorless TMC drivers.

### ⚠️ The Scavenger’s Safety Protocol

* **Toner is Toxic:** Always wear gloves and a mask when opening a laser printer. Toner is an ultra-fine plastic powder that is "icky" for your lungs.
* **Check the Rods:** Before taking a rod home, roll it on a flat piece of glass. If it wobbles or light shines under it, it's bent and useless for a 3D printer.
* **Cleaning:** Scavenged rods often have "black goo" (a mix of old oil and dust). Clean them with isopropyl alcohol and a light sand with 1200-grit paper if they have any surface oxidation.

---

### What I can do next for your project:

Since you’re using **build123d** to create a parametric "webservice," would you like me to:

1. **Draft the Python logic** for how the script should handle the "8mm vs 10mm" rod diameter choice in the STL generation?
2. **Help design the questionnaire flow** that users will fill out to generate their "bespoke" manual?
3. **Refine the "Triple-Z" Klipper configuration** logic so it's easy for a beginner to paste into their `printer.cfg`?

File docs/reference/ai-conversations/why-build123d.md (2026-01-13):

Settling on **build123d** is a sophisticated choice that aligns perfectly with a "software-first" engineering mindset. While tools like OpenSCAD pioneered "CAD-as-code," build123d represents a generational leap by moving from basic constructive geometry to a full **BREP (Boundary Representation)** kernel (OpenCascade) within a standard Python environment.

Below is a comparison to help justify this decision in your ADR and documentation.

---

### Comparison of CAD Paradigms

| Feature | **TinkerCAD** | **FreeCAD (GUI)** | **OpenSCAD** | **build123d** |
| --- | --- | --- | --- | --- |
| **Core Paradigm** | Simple CSG (Visual) | BREP (Feature Tree) | Scripted CSG | **Scripted BREP** |
| **Language** | None (Drag/Drop) | Python (Optional) | OpenSCAD (Domain) | **Python (Native)** |
| **Geometry** | Meshes | Precise NURBS | Meshes/CSG | **Precise NURBS/STEP** |
| **Selection** | Mouse | Mouse (Unstable) | Manual Math | **Smart Selectors** |
| **Version Control** | Poor | Difficult (Binary) | Excellent (Text) | **Excellent (Python)** |

---

### Why the others were likely rejected

#### 1. OpenSCAD (The "Old Guard" of Code-CAD)

* **The Math Tax:** OpenSCAD doesn't "know" where a face or edge is. If you want to put a hole 5mm from the edge of a block, you have to keep track of the block's coordinates in your head. If the block size changes, you must update the math manually.
* **Fillet/Chamfer Nightmare:** Because it uses CSG (adding/subtracting shapes), doing a simple fillet on a complex edge is mathematically exhausting and often renders slowly.
* **Non-Standard Language:** You have to learn a proprietary, functional language that doesn't exist outside of OpenSCAD.

#### 2. FreeCAD & GUI Systems

* **The "Topological Naming" Problem:** In FreeCAD, if you change a dimension early in the tree, the internal names of faces often "shuffle." This breaks all subsequent features (your hole is suddenly on the wrong side).
* **Hard to Automate:** While FreeCAD has a Python API, it is bolted onto a GUI-first workflow, making it "clunky" for a pure CLI build system like yours.

---

### Why build123d is "The Future"

**Build123d** feels like the future because it treats 3D design like **modern software engineering**.

1. **Object Awareness (The BREP Advantage):** Unlike OpenSCAD, build123d understands topology. You can tell the script: *"Find the top-most face and fillet all edges that are parallel to the X-axis."* If the part grows or shrinks, the script still finds that face correctly.
2. **Native Python Power:** You aren't limited to a niche CAD language. You can use `pip install` to bring in NumPy for complex math, `requests` to pull data from an API, or `logging` to debug your build.
3. **The "Builder" vs. "Algebra" Modes:** It offers a "Builder" context (using `with` statements) that mimics how humans think about building—*“I am working on this face, now I am sketching here”*—making the code highly readable.
4. **Professional Output:** It exports true **STEP files**, which are the industry standard for CNC and professional manufacturing. OpenSCAD is largely stuck in the world of STL (meshes).

---

### Integration with Quarto

Since you are using **Quarto**, your choice of build123d is even more powerful. Quarto is built to execute Python code cells and render the results.

* **Literate CAD:** You can write your assembly documentation in Quarto and include the actual build123d code snippets.
* **Automated Diagrams:** You can use a Python library (like `cq-editor` or `ocp-vscode` helpers) to capture renders of your parts during the Quarto render process.
* **Single Source of Truth:** Your documentation and your 3D geometry can live in the same `.qmd` or `.py` files.

**Would you like me to help you draft the "Rationale" section of your ADR, specifically highlighting how build123d solves the "Topological Naming" issues found in other systems?**

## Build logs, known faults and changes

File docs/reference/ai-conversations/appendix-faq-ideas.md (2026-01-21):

# Document 1: One‑Page Design Philosophy

## Purpose

This project exists to enable people to **build capable, high‑quality 3D printers using scavenged, reused, and widely available parts**, without sacrificing print quality or requiring specialised supply chains.

The goal is not to build the *fastest*, *lightest*, or *most precise* printer. The goal is to build a **printer that many people can realistically build, understand, modify, and maintain**.

---

## Core Principles

### 1. Accessibility over Optimisation

Design choices prioritise **availability, simplicity, and reuse** over theoretical performance gains. If a part is difficult to source, proprietary, or requires a specialised kit, it cannot be a reference component.

A design that performs 95% as well but is buildable by twice as many people is the superior design.

---

### 2. No Quality Penalty for Lower Tiers

All build tiers must be capable of producing **equivalent print quality**.

Higher tiers reduce:

* wiring complexity
* sourcing difficulty
* configuration effort

They **do not** unlock better prints.

Lower‑tier builders are not building an inferior printer — they are building the *same printer* with more effort and ingenuity.

---

### 3. Scavengability Is a First‑Class Requirement

Reference designs must:

* tolerate part variation
* accept imperfect or reused components
* work with metric hardware commonly found in old printers, appliances, or office equipment

If a design assumes precision parts or narrow tolerances, it is optional by definition.

---

### 4. Mechanical Honesty

The printer should be understandable as a machine.

Designs should:

* expose how forces flow
* favour visible, inspectable mechanisms
* avoid hidden complexity

This supports learning, debugging, and modification — key RepRap values.

---

### 5. Evolution, Not Replacement

The printer is designed to evolve:

* parts may be replaced
* subsystems may be upgraded
* configurations may vary

But **the core architecture remains stable**, so improvements do not fragment the ecosystem.

---

## Philosophy Summary (Short Form)

> *Build the simplest machine that prints well, using the parts people already have, and allow complexity only where it genuinely reduces burden — never just because it is possible.*

---

# Document 2: Reference vs Optional Component Policy

## Purpose

This policy defines how components are classified to ensure:

* fairness across build tiers
* consistent documentation
* long‑term maintainability
* minimal supply‑chain dependency

---

## Reference Components

A **Reference Component** is the baseline expectation for all builds.

### A component may be Reference if it:

* is fully printable or uses generic hardware
* can be built without proprietary or precision kits
* is tolerant of part variation
* is reasonably achievable through scavenging or common suppliers
* does not impose a print‑quality advantage over alternatives

### Reference components must:

* be documented first
* be supported across all tiers
* define the mechanical and electrical assumptions of the printer

### Example:

* **Extruder:** Pitan (printed gears, generic hardware)

---

## Optional Components

An **Optional Component** is a valid alternative that:

* improves ease of assembly, compactness, or aesthetics
* appeals to experienced builders or tinkerers
* may require purchased kits or specialised parts

Optional components **must not**:

* be required for acceptable print quality
* invalidate reference documentation
* create a perception that reference builds are inferior

### Optional components are explicitly non‑normative.

They are *choices*, not expectations.

---

## Classification Rules

A component is **Optional by default** unless it clearly satisfies all Reference criteria.

If a component:

* requires a gear kit, belt kit, or custom shaft
* depends on narrow tolerances
* assumes new parts availability

…it cannot be Reference.

---

## Extruder Policy (Concrete Example)

### Reference Extruder

* Pitan
* Generic NEMA17 motor
* Printed gears
* Generic bearings and fasteners

### Optional Extruders

* Orbiter v1.5
* Voron M4
* Wristwatch
* ProtXtruder

These options:

* do not materially improve print quality
* increase sourcing complexity
* are therefore excluded from the reference spec

---

## Tier Consistency Rule

Across Tier 1, Tier 2, and Tier 3:

* kinematics remain identical
* extrusion concept remains identical
* motion quality expectations remain identical

Tiers exist to reduce **logistical burden**, not to gate capability.

---

## Policy Summary

> *Reference defines what everyone can build. Optional defines what some may enjoy building. Confusing the two undermines the project.*

---

# Appendix: Extruder Topology Rationale

## Single‑Drive vs Dual‑Drive Extruders

The Neo‑Darwin reference design deliberately adopts a **single‑drive extruder topology**.

This decision is not based on cost alone, but on mechanical behaviour, tolerance to variation, and long‑term stability across scavenged and mixed‑quality components.

### Single‑Drive Characteristics

A single‑drive extruder uses one driven hobbed gear and a spring‑loaded idler to grip filament.

This topology:

* has a single torque source
* introduces only one periodic error source
* is tolerant of minor misalignment
* fails gradually and visibly

Any compliance or elasticity in the system is smooth and continuous, making it easy to compensate using firmware features such as pressure advance.

### Dual‑Drive Characteristics

Dual‑drive extruders use two opposing driven gears that must mesh correctly and remain synchronised under load.

This introduces additional dependencies:

* matched gear tooth profiles
* precise centre‑to‑centre spacing
* consistent preload
* uniform wear between gears

Small mismatches between gears — especially in printed or mixed‑quality parts — can introduce torque ripple or micro stick‑slip behaviour. These effects are difficult to detect, difficult to diagnose, and can subtly affect extrusion consistency.

### Design Conclusion

Dual‑drive extruders primarily increase **extrusion force and filament handling robustness**, not surface finish or dimensional accuracy.

For the extrusion forces required by the Neo‑Darwin reference design, a single‑drive system provides sufficient grip with fewer failure modes, greater tolerance to part variation, and lower mechanical complexity.

For these reasons, single‑drive extrusion is selected as the reference topology.

---

# FAQ Entry: Why Not Dual‑Drive Extruders?

**Q: Why does the Neo‑Darwin project not use a dual‑drive extruder as the reference?**

**A:** Dual‑drive extruders primarily improve extrusion force and filament grip, which is valuable for very soft filaments or extreme flow‑rate scenarios. However, they also introduce additional mechanical complexity and dependence on precise gear meshing.

For the materials and print speeds targeted by Neo‑Darwin, a single‑drive extruder provides equivalent print quality while being more tolerant of scavenged parts, easier to assemble, and easier to maintain. Because dual‑drive systems do not materially improve print quality for the reference use case, they are treated as optional rather than reference components.

Builders interested in experimenting with dual‑drive designs are free to do so, but the reference specification prioritises simplicity, robustness, and accessibility over theoretical performance gains.

---

# FAQ Entry: Why Not CoreXY?

**Q: Why does the Neo-Darwin project use a Cartesian motion system instead of CoreXY?**

**A:** CoreXY is an efficient and capable motion system, but it introduces additional belt paths, alignment sensitivity, and tuning complexity. These factors increase the build and debugging burden, particularly when using scavenged or mixed-quality components.

The Neo-Darwin project prioritises:

* mechanical clarity
* ease of diagnosis
* tolerance of part variation
* predictable behaviour under imperfect assembly

A fixed-gantry Cartesian layout achieves equivalent print quality at the speeds and accelerations targeted by the project, while remaining easier to understand, assemble, and repair. Because CoreXY does not materially improve print quality for the reference use case, it is treated as optional rather than reference.

---

# FAQ Entry: Why Smooth Rods Instead of Linear Rails?

**Q: Why does the reference design use smooth rods instead of linear rails?**

**A:** Linear rails offer high stiffness and compactness, but they require clean environments, careful alignment, and consistent lubrication to perform reliably. Scavenged rails vary widely in condition and are difficult to evaluate visually.

Smooth rods and linear bearings:

* are widely available from donor printers and office equipment
* tolerate minor misalignment
* fail gradually and visibly
* are easier to clean, replace, and realign

For the spans and loads used in the Neo-Darwin reference design, smooth rods provide sufficient stiffness without introducing additional sourcing or maintenance burden. Linear rails are therefore supported as optional upgrades, but not required for reference builds.

---

# Appendix: Motion System Load Budget

## Purpose

This appendix defines acceptable mass limits for moving components to ensure predictable motion behaviour across all build tiers.

The motion system is designed to operate within conservative stiffness margins using M8 or M10 smooth rods without mid-span supports.

---

## Reference Toolhead Load

The reference toolhead consists of:

* Pitan extruder (printed)
* NEMA17 stepper motor
* Standard V6-style hotend or equivalent
* Mounting hardware

**Target mass:**

* ~220–260 g (depending on motor and material choice)

This load remains within acceptable deflection limits for:

* M8 smooth rods at ≤280 mm span
* M10 smooth rods at ≤250 mm span

---

## Non-Reference Loads

Heavier toolheads increase dynamic deflection, acceleration sensitivity, and tuning burden.

Designs that exceed the reference load budget may:

* require reduced spans
* require additional structural support
* impose stricter acceleration limits

Such designs are therefore classified as **Optional**.

---

## Design Rule

> Reference components must not exceed the motion system load budget or require structural compensation to function correctly.

This ensures that motion quality and print consistency are preserved across all tiers without additional complexity.

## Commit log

2026-01-11 Add Z-puck and frame geometry clarifications
    User feedback - adopt all three improvements:
    1. **Integrated Corner Z-Pucks**:
    - Combine corner bracket + Z-motor mount into one part
    - Reduce parts: 11 → 4 corners
    - Simpler assembly, stronger design, less tolerance stacking
    2. **Symmetric Triangle Pattern**:
    - Change from Front L + Back L + Back C
    - To Front L + Front R + Back C (centered)
    - Benefits: Even weight distribution, less bed sag/warp
    - Better stability, symmetric load on all 3 motors
    3. **Reduced Frame Height**:
    - Current: 330mm → Proposed: 300mm
    - Reason: M12 is very stiff, extra height adds cost/vibration
    - Z-travel: 280mm → 260mm (still suffi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
2026-01-11 Fix corner count - only 4 corners not 8
    User correction: We need 3 Z-motors total, not 4.
    Corrected corner breakdown:
    - Front Left corner: Z-mount integrated (Z1 motor)
    - Front Right corner: Z-mount integrated (Z2 motor)
    - Back Center vertical rod: Z-puck (Z3 motor) - NOT a corner!
    - Back Left corner: Standard corner (no Z-motor)
    - Back Right: NOT EXIST (frame has 3 vertical rods on back edge)
    Total corners: 4 (not 8)
    Z-motors: 3 (Front L + Front R + Back Center)
    This reduces parts from 11 to 4, simpler assembly.
2026-01-11 Fix frame geometry - 8 vertical rods, 5 total parts
    User correction - frame has 8 vertical rods, not 4 corners:
    Frame structure:
    - FRONT: 4 vertical rods (FL, FCL, FCR, FR)
    - BACK: 4 vertical rods (BL, BCL, BCR, BR)
    - Total: 8 vertical rods (not just 4!)
    Z-motor mounting (corrected):
    - Z1: Integrated into Front-Left corner
    - Z2: Integrated into Front-Right corner
    - Z3: Separate Z-puck on back bottom horizontal rod (NOT back center vertical!)
    Back corners:
    - Back-Left: Standard corner (no Z-motor)
    - Back-Right: Standard corner (no Z-motor)
    - Back-center vertical rod: Z3 motor mount point
    Total parts: 4 corners + 1 Z-puck = 5 (not 11!)
    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
2026-01-11 Confirm 9 frame parts - ready for Phase 2 design
    Final frame parts count:
    - 2 front Z-mount corners (Front L + Front R)
    - 2 back standard corners (Back L + Back R)
    - 1 Z-puck (back center on bottom horizontal rod)
    - 4 top corners (TL, TR, BL, BR for gantry)
    Total: 9 printed frame parts
    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
2026-01-11 Add Corner 2 (Front-Right + Z2) and update status
    Corner 2: Front-Right with integrated Z2 motor
    - Mirror of Corner 1
    - Integrated NEMA17 Z2 mount
    - 4× M12 rod clamps
    - Leadscrew vertical path
    - Jam nut access holes
    Status update: 2/9 parts (22%) complete
2026-01-11 Fix master.sh syntax errors, add Voron assembly manual note
    Fixed bash syntax errors in master.sh build script.
    Added missing ;; to close case statement.
    Script now works correctly for list command.
    Note: Downloaded Assembly_Manual_Trident.pdf from Voron repository
    at /Users/michael/Downloads/Assembly_Manual_Trident.pdf for reference.
2026-01-11 Add comprehensive BUILDING.md guide and update README
    - Create BUILDING.md with complete build workflow documentation
    - Add Getting Started section to root README
    - Document three build pathways (automated, manual, existing env)
    - Include troubleshooting section for common issues
    - Explain parametric design philosophy and why not download STLs
    - Add system requirements and platform-specific setup
    - Link to BUILDING.md from README for detailed instructions
    New user experience:
    1. Clone repo
    2. See README Getting Started section
    3. Navigate to cad/ and run ./setup.sh
    4. Follow BUILDING.md for complete guide
    Build process is now fully documented and user-friendly.
2026-01-11 Switch to modern Python packaging: pyproject.toml instead of requirements.txt
    - Create pyproject.toml with build123d>=0.9.0, numpy>=1.20.0
    - Delete legacy requirements.txt (avoiding confusion with two files)
    - Update build.sh to use pyproject.toml (uv pip install -e . or pip install -e .)
    - Update BUILDING.md and cad/README.md to reference pyproject.toml
    - Update Python version requirement to 3.14+ (for build123d 0.9.x)
    - Fixed parts/corner_motorized.py to import from correct path
    Benefits:
    - Modern PEP 621 packaging standard
    - Single dependency file (no confusion)
    - Works seamlessly with both uv and pip
    - Better future compatibility
    Users just run ./build.sh, scripts handle everything aut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
2026-01-11 Add dynamic part discovery and test mode for build system
    - Create parts/list.py for automatic part discovery
    - Update build.sh to use dynamic discovery from parts/*.py
    - Add TEST_MODE flag for testing with subset of parts
    - Update documentation with test mode usage
    - Add Assembly_Manual_Trident.pdf to .gitignore (large file)
    Dynamic discovery benefits:
    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
2026-01-11 Reorganize part structure: shared utilities + individual corners
    - Create include/ folder for shared build123d components
    - corner_components.py: reusable motorized corner components
    - Create parts/corner/ folder for individual corner parts
    - Move list.py from parts/ to include/ (dynamic part discovery)
    - Create corner_front_left.py importing from shared utilities
    - Delete corner_motorized.py (was multi-file, now modular)
    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
2026-01-11 Add standard corner with proper config handling
    - Create corner_standard.py with M12 rod clamps
    - Add corner parameters to config.py (CORNER_SIZE, WALL_THICKNESS, JAM_NUT_ACCESS_DIA)
    - Remove fallback values - exit with error if config.py missing
    - Fix STL export path to use stl/ directory
    - Add stl/*.stl to .gitignore
2026-01-13 docs: Add reference articles and AI conversations
    Add organized documentation from reference/ai-conversations/:
    - Core engineering discussions for all major ADRs
    - Historical decision context
    - Technical analysis and trade-off discussions
    Add docs/articles/:
    - wisdom.md: Core engineering principles
    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
2026-01-21 Add documents before restructure
    [calibration_tractor_final.stl, toy_tractor.stl, toy_tractor_only.scad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]
2026-01-21 docs: Major documentation restructure and spec updates
    Phase 1 - ADR Updates:
    - Archive ADR-002 (Greg's Wade), create ADR-019 (Pitan extruder)
    - Rename ADR-001 from M12 to M10 skeleton with rationale
    - Update ADR README index and reading order
    - Fix typo: traxctor_06 -> tractor_06
    Phase 2 - Documentation Restructure:
    - Split MANIFESTO.md (56KB) into three focused documents:
    - MANIFESTO.md: Quick-start overview (3.6KB)
    - PHILOSOPHY.md: Tractor philosophy and RepRap wisdom
    - REFERENCE-SPEC.md: Hardware specification (M10, Pitan)
    - Create new folder structure:
    - docs/deep-dives/: Design explorations (moved tractor_* files)
    - docs/guides/: Tier-specific build guides (scaffold)
    - doc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
2026-01-27 feat: Add dual-8 motion system as reference spec with comprehensive ADRs
    Major specification update based on Voron Legacy analysis showing that
    dual 8mm rods with shared load achieve equal or better deflection than
    single 10mm rods, enabling full scavengeability from 2 donor printers.
    New ADRs:
    - ADR-020: Dual-8 Scavenger Variant (superseded, analysis preserved)
    - ADR-021: Dual-Rod Motion System (new reference spec)
    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
2026-01-27 docs: Add donor 3D printer compatibility guide
    Comprehensive guide for identifying valuable donor printers:
    - Tier A (rod-bearing): Anet A8, Prusa clones, Anycubic i3 Mega
    - Tier B (V-slot): Ender 3, CR-10, Voxelab, Artillery
    - Tier C (limited): Prusa Mini, small/specialty printers
    For each donor type, documents:
    - Smooth rods, bearings, motors, beds, PSU, mainboard
    - What's directly usable vs needs replacement
    - Yield from dual-donor combinations
    - "The Ender 3 Gap" - $73 for stainless + IGUS
    Includes hunting tips, where to find donors, pre-teardown
    checklist, and recommended donor combinations.
    References ADR-012, ADR-021, ADR-022, ADR-024.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
2026-01-27 docs: Improve heritage acknowledgments with specific technical contributions
    Update PHILOSOPHY.md and ADR-000 to be explicit about what was borrowed
    from each heritage project:
    - RepRap Darwin (2007): Box-frame threaded-rod skeleton
    - RepRap Mendel (2009): "Plough" X-carriage sled on dual rods
    - Prusa i3 Rework (2013): Greg's Wade geared extruder (Pitan ancestor)
    - Voron Legacy: Dual 8mm rods with vertical stacking (ADR-021)
    - Voron Trident: Three-pillar Z-drop, Triple-Z leveling (ADR-005, ADR-023)
    - The 100: Klipper-first philosophy
    - The Rook: Box-frame serviceability
    Adds "Technical Ancestors" table showing specific contributions.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
2026-01-28 docs: Add ADR-026 (Donor Fitness Constraints) with fitness tiers and frame compatibility
    - ADR-026: Define fitness tiers (Tier 1: 200-235mm bed, <280mm Z; Tier 2: 235-300mm with mitigation; Tier 3: unsupported)
    - Physics-based stability constraints for Z-height and bed size
    - Heatbed swap guidance for Tier 2 donors (CR-10, Artillery)
    - Enhanced donor-printer-guide with fitness context for all donors
    - Correct frame types: Anycubic i3 Mega (steel, not extrusion), Prusa i3 clones (all steel rod-based)
    - Clarify Prusa MK2/3 not ideal as donors (integrated design; better to just add Klipper)
    - Add cross-references to projects with own communities (Ender 5, large Tronxy, Prusa)
    - Update ADR READM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
2026-01-29 docs: Add standalone Parts Sourcing & Replacement Guide
    New document: docs/reference/parts-sourcing-guide.md
    Addresses real-world scenario: You've got your donors and started assembly, only to
    discover a PSU is dead, a leadscrew is bent, or bearings are worn. This guide teaches
    how to source replacement parts without getting scammed.
    Content:
    - Common parts you'll likely need to source (M10 rods, M8 leadscrews, bearings, PSU, etc.)
    - How to spot counterfeits and duds on AliExpress, Temu, eBay
    - Red flags vs. green flags for part listings
    - Common pitfalls: wrong lead screw pitch (T8 2mm vs 8mm), counterfeit bearings,
    mixed pack sizes, wrong PSU voltage, shipping delays
    - Platform compari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
2026-01-29 docs: Add cross-references to Parts Sourcing Guide in Donor Guide
    Added two callouts in donor-printer-guide.md:
    1. In intro (after Cost Reality Check):
    "Budget for Contingencies: Expect to spend $80-150 on parts you can't scavenge
    (M10 rods, M8 leadscrews, bearings, PSU, misc). See Parts Sourcing & Replacement
    Guide for how to source these if a donor part fails or is damaged.
    Total realistic budget: $250-380 AUD."
    2. In Recommended Donor Combinations section:
    Warning that cost breakdowns are best-case (all donor parts usable).
    Budget additional $80-150 for parts you'll source.
    Forward reference to Parts Sourcing Guide.
    Realistic total: $250-380 AUD.
    This connects t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
